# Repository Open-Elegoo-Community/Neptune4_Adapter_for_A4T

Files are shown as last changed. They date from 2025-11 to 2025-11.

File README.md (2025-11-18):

# A4T Adapter for Elegoo Neptune 4  
A toolhead adapter by **Beattune**

> [!NOTE]  
> This adapter supports the **Elegoo Neptune 4** with the original **POM-wheel carriage**.  
> The **Elegoo Neptune 4 Pro** is currently untested and therefore not officially supported.

<p align="center">
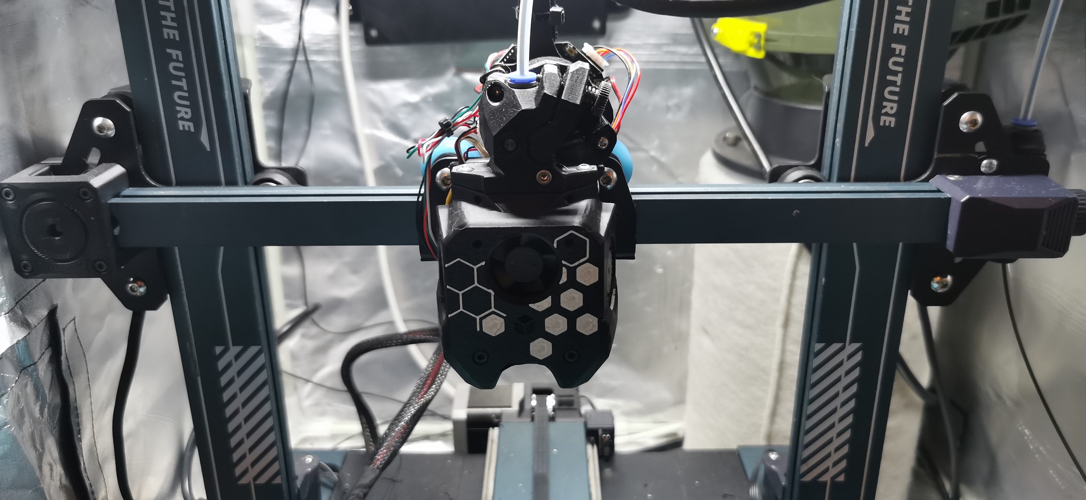
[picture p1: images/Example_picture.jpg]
  
</p>

## Overview

The Elegoo Neptune 4 is a fast and reliable 3D printer, but the available hotends for the stock or custom tool heads are limited.  
The original POM-wheel carriage does not support many well-known high-flow tool heads, which is why this adapter was created.  

This adapter allows you to mount a wide range of popular tool heads using the **Voron CW2 mount pattern**.  
It is optimized for use with the **[A]nother [4]010 [T]oolhead**, offering excellent hotend support and highly efficient airflow due to CFD-optimized 4010 fan ducts.

There is **no loss in X or Y build volume**, and — depending on cable routing — **no loss in Z height** either.

- More information about **A4T**:  
  https://github.com/Armchair-Heavy-Industries/A4T

You can configure your ideal setup using the **A4T Web Configurator**:  
https://a4t.wizards-enclave.net/  
When using the configurator, make sure to select **Voron Tap** as the carriage option.  
All other settings are up to you.  
If you plan to add **Neopixel LEDs** to your A4T, note that the stock tool head breakout board cannot be used.

### Recommended Setup (Used and Verified by Me)

- **Extruder:**  
  [Wristwatch BMG for A4T](https://github.com/Armchair-Heavy-Industries/A4T/tree/main/STL/WW-BMG%20for%20A4T)
- **Extruder Stepper:**  
  [Moons CSE14HRA1L410A-02](https://de.aliexpress.com/item/1005005870658160.html)  
  (The original extruder stepper can be reused but is weaker than a Moons 8-tooth stepper.)
- **Hotend:**  
  [Triangle Labs Dragon Ace Volcano](https://trianglelab.net/products/dragon-ace%E2%84%A2-hotend?VariantsId=12006)  
  Use **104NT-4** with the original breakout board, otherwise choose **PT1000**.
- **PCB Mount:**  
  [LDO NightHawk36](https://de.aliexpress.com/item/1005007544684952.html)  
  (If preferred, the stock Elegoo breakout board can also be reused — a compatible mount is available [here](https://github.com/Open-Elegoo-Community/Neptune4_A4T_accessories).)
- **Part Cooling Fans:**  
  [GDStime 12,000 RPM (24 V)](https://www.aliexpress.com/item/1005005094153190.html)
- **Hotend Fan:**  
  [HoneyBadger Performance 2510 Axial (24 V)](https://www.fabreeko.com/collections/axial-fan/products/2510-performance-axial-fan-by-honeybadger)

---

## Bill of Materials (BOM)

| QTY | Item | Notes |
| --- | ---- | ----- |
| 6 | M3 threaded heat-set insert (Ø4.5 mm OD, 4 mm length) | BTT Eddy version requires only 5 |
| 2 | M3×8 mm SHCS | Mounting adapter to the POM-wheel carriage |
| 1 | M4×12 mm BHCS | Additional bottom mounting screw |
| 1 | M4 tap wrench | Required for cutting the M4 thread in the POM carriage |

---

## Printing the Parts

The parts were designed for a **0.2 mm layer height**.  
A first layer of **0.25 mm** works well. Other layer heights have not been tested and may lead to unexpected tolerance issues.

Print settings depend on your machine and filament. The model is **not pre-scaled** for shrinkage compensation — you may need to tune your filament for a precise fit.  
Development and testing were done using **Elegoo ASA** and **Fiberlogy ASA** (each individually tuned).

### Verified Print Settings

- Layer height: **0.2 mm**
- Line width: **0.4 mm**
- Wall loops: **6**
- Top layers: **10**
- Bottom layers: **10**
- Infill density: **40%**
- Infill pattern: **Honeycomb or Triangle**

Since this part is a structural adapter for your tool head, prioritize **strength** and **layer adhesion**.

---

## Assembly Guide

### 1. Remove the Original Tool Head
- Disconnect the tool head cable.  
- Remove the rear screws securing the tool head to the carriage.  
- Remove the front screws.  
- Lift off the original tool head.

### 2. Remove the POM-Wheel Carriage
> [!NOTE]  
> If you are using a **Neptune 4 Pro**, you may skip this step and Step 3.

- Disassemble the top two POM wheels.  
- Remove the X-axis belt from the carriage.  
- Remove the POM-wheel carriage.

### 3. Add the M4 Thread to the POM-Wheel Carriage
- Cut an M4 thread into the **bottom center standoff**.  
- Thoroughly clean the POM-wheel carriage afterwards.  
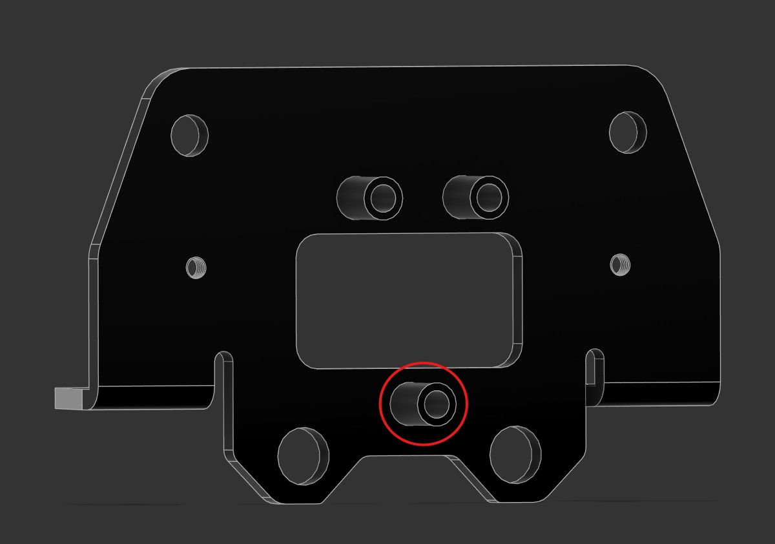
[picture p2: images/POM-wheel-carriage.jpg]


### 4. Reassemble the POM-Wheel Carriage
- Mount the carriage back onto the X-extrusion and reinstall the top POM wheels.  
- Verify proper wheel alignment: motion should be smooth with **no detectable wobble**.  
- Reattach the X-axis belt.

### 5. Assemble the A4T Adapter
- Install the M3 heat-set inserts (see picture).  
- Place the adapter onto the POM carriage; it will align over the two metal standoffs.  
- Insert **two M3×8 mm screws** (left + right) and thread them loosely.  
- Insert **one M4×12 mm screw** into the bottom hole and thread it loosely.  
- Tighten all screws in this order:  
  **1. M4 bottom → 2. Left M3 → 3. Right M3**

### 6. Assemble the A4T Tool Head
Follow the official assembly instructions:  
https://github.com/Armchair-Heavy-Industries/A4T?tab=readme-ov-file#assembly

---

## Credits

Thanks to everyone who contributed ideas, feedback, or testing to make this adapter possible!

---

## Enjoy Your A4T!

Have fun using your A4T tool head with the Elegoo Neptune 4! If you have improvements or suggestions, feel free to open an issue or contribute to the project.

[def]: /images/POM-wheel-carriage.jpg

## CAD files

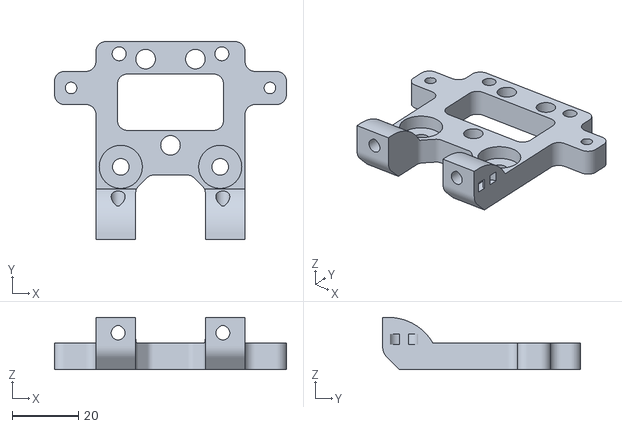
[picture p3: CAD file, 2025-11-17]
STL/Adapter with Beacon or Cartographer probe/A4T Adapter plate for N4 original carrier w carto-beacon.stl
70.0 x 59.7 x 15.8
